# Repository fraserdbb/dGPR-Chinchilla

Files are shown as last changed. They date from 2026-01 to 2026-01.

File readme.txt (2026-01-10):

Novel Application of Stereotaxically Guided Dental Germinative 
Photodynamic Regulation in Chinchilla lanigera with 
Refractory Malocclusion.

Authored and Developed by Daniel B. B. Fraser

DOI: https://doi.org/10.5281/zenodo.18203469

~~~~~~~~~~~~~~~~~~~~~~~~~~~~~~~~~~~~~~~~~~~~~~~~~~~~~~~~~~~~~~~~~~~~~~~~~

This repository contains an open-source paper which covers photodynamic
therapy as a potential treatment option for refractory malocclusion
cases in chinchillas and other elodonts, particularly in cases of 
excessive growth, inadequate wear, and retrograde elongation.

There is also supporting documentation providing details on a
patient-specific stereotaxic device, dubbed Auriel, which was designed
to provide a stable, secure platform for the procedure. The model files
for this device are not released, to prevent it from being used against
advisement on chinchillas that it was not designed for.

Lastly, there is an attached software package for the validation of MCX
simulations graphed in the appendix of the paper. These are validation
structures with exact command line arguments for the user to enter, to
allow for exact reproducibility.

~~~~~~~~~~~~~~~~~~~~~~~~~~~~~~~~~~~~~~~~~~~~~~~~~~~~~~~~~~~~~~~~~~~~~~~~~

Further details on the software package can be found in the readme files
contained in each subfolder.

~~~~~~~~~~~~~~~~~~~~~~~~~~~~~~~~~~~~~~~~~~~~~~~~~~~~~~~~~~~~~~~~~~~~~~~~~

License & Copyright

This project is dual-licensed due to scope:

Software code (Python Scripts) are licenced under the GNU General Public
License v3.0 (GPLv3). You may copy, distribute, and modify the software as
long as you track the changes and release modifications under the same 
license.

Documentation and Papers (PDFs, Protocol Text, and Guide Specifications) 
are licensed under Creative Commons Attribution-ShareAlike 4.0
International (CC BY-SA 4.0). To view a copy of this license, visit 
https://creativecommons.org/licenses/by-sa/4.0/

~~~~~~~~~~~~~~~~~~~~~~~~~~~~~~~~~~~~~~~~~~~~~~~~~~~~~~~~~~~~~~~~~~~~~~~~~

Bibliography

The following works were cited in the development of this protocol,
hardware design, and simulation. For a formatted list with embedded links
download the main paper PDF, which is listed under the name
"Fraser_dGPR_Chinchilla_Protocol_2025_RELEASE.pdf"

Agostinis, P. et al. (2011). Photodynamic Therapy of Cancer: an Update. CA: a Cancer Journal for Clinicians, 61, 250-281. https://doi.org/10.3322/caac.20114

Anderson, R. R. & Parrish, J. A. (1983). Selective Photothermolysis: Precise Microsurgery by Selective Absorption of Pulsed Radiation. Science, 220(4596), 524-527. https://doi.org/10.1126/science.6836297

Bisland, S. K. & Burch, S. (2006). Photodynamic Therapy of Diseased Bone. Photodiagnosis and Photodynamic Therapy, 3(3), 147-155. https://doi.org/10.1016/s1572-1000(06)00036-6

Brenner, S. Z. G. et al. (2005) Clinical Anatomy, Radiography, and Computed Tomography of the Chinchilla Skull. Compendium on Continuing Education for the Practicing Veterinarian. 27(12), 933-943.

Brodbelt, D. C. et al. (2008). The Risk of Death: the Confidential Enquiry into Perioperative Small Animal Fatalities. Veterinary Anaesthesia and Analgesia, 35(5), 365-373. https://doi.org/10.1111/j.1467-2995.2008.00397.x

Capello, V. (2016). Diagnostic Imaging of Dental Disease in Pet Rabbits and Rodents. The Veterinary Clinics of North America. Exotic Animal Practice, 19(3), 757-782. https://doi.org/10.1016/j.cvex.2016.05.001

Cooper, G. (1975). Anatomy of the Guinea Pig. Harvard University Press. p. 151. ISBN 9780674031593.

Crossley, D. A. (2001). Dental Disease in Chinchillas in the UK. The Journal of Small Animal Practice, 42(1), 12-19. https://doi.org/10.1111/j.1748-5827.2001.tb01977.x

Dolmans, D. et al. (2003). Photodynamic Therapy for Cancer. Nature Reviews Cancer, 3, 380-387. https://doi.org/10.1038/nrc1071

Eriksson, A. R. & Albrektsson, T. (1983). Temperature Threshold Levels for Heat-Induced Bone Tissue Injury: A Vital-Microscopic Study in the Rabbit. The Journal of Prosthetic Dentistry, 50(1), 101-107. https://doi.org/10.1016/0022-3913(83)90174-9

Fang, Q. & Boas, D. A. (2009). Monte Carlo Simulation of Photon Migration in 3D Turbid Media Accelerated by Graphics Processing Units. Optics Express, 17(22), 20178-20190. https://doi.org/10.1364/oe.17.020178

Fu, Y & Jacques, S. L. (2011). Monte Carlo Simulation for Light Propagation in 3D tooth model. Optical Interactions with Tissues and Cells XXII, SPIE: Bellingham, WA, USA. https://doi.org/10.1117/12.873603

Greene, E. C. (1935). Anatomy of the Rat. Transactions of the American Philosophical Society, 27. https://doi.org/10.2307/1005513

Harada, H. et al. (1999). Localization of Putative Stem Cells in Dental Epithelium and their Association with Notch and EGF Signaling. The Journal of Cell Biology, 147(1), 105-120. https://doi.org/10.1083/jcb.147.1.105

Harris, K. et al. (2017). Endobronchial Ultrasound-Guidance for Interstitial Photodynamic Therapy of Locally Advanced Lung Cancer – A New Interventional Concept. Journal of Thoracic Disease, 9(8): 2613-2618. https://doi.org/10.21037/jtd.2017.07.45

Hisey, E., et al. (2024). Contrast Computed Tomography Dacryocystorhinography Identifies Nasolacrimal Duct Obstruction Secondary to Chronic Dental Disease in Two Chinchilla lanigera. Veterinary Ophthalmology, 28(3). https://doi.org/10.1111/vop.13281

Kato, T., et al. (2017). Nanoparticle Targeted Folate Receptor 1-Enhanced Photodynamic Therapy for Lung Cancer. Lung Cancer 113: 59-68. https://doi.org/10.1016/j.lungcan.2017.09.002

Krammer, B. (2001). Vascular Effects of Photodynamic Therapy. Anticancer Research 21(6B), 4271-4277.

Legendre, L. F. J. (2002). Malocclusions in Guinea Pigs, Chinchillas and Rabbits. The Canadian Veterinary Journal or La Revue Veterinaire Canadienne, 43(5), 385-390. 

Lennox, A. M., et al. (2021). 36 - Small Mammal Dentistry. Ferrets, Rabbits, and Rodents, 4th Edition: 514-535. ISBN 9780323484350, https://doi.org/10.1016/B978-0-323-48435-0.00036-8

Lovell, J. F. et al. (2011). Porphysome Nanovesicles Generated by Porphyrin Bilayers for Use as Multimodal Biophotonic Contrast Agents. Nature Mater, 10, 324-332. https://doi.org/10.1038/nmat2986

Mans, C. & Donnelly, T. M. (2021). 22 - Chinchillas. Ferrets, Rabbits, and Rodents, 4th Edition: 298-322. ISBN 9780323484350, https://doi.org/10.1016/B978-0-323-48435-0.00022-8

Natural History Museum of Los Angeles County (2020). Chinchilla lanigera Skull DICOM [Data Set]. MorphoSource. https://www.morphosource.org/concern/media/000114253

Philp, L. et al. (2019). Use of Porphysomes to Detect Primary Tumour, Lymph Node Metastases, Intra-Abdominal Metastases and as a Tool for Image-Guided Lymphadenectomy: Proof of Concept in Endometrial Cancer. Theranostics 9(9). 2727-2738. https://doi.org/10.7150/thno.31225

Ritzman, T. (2014). Diagnosis and Clinical Management of Gastrointestinal Conditions in Exotic Companion Mammals (Rabbits, Guinea Pigs, and Chinchillas) Veterinary Clinics of North America: Exotic Animal Practice 17(2), 179-194. https://doi.org/10.1016/j.cvex.2014.01.003

Sadar, M. J. & Mans, C. (2023). Hystricomorph Rodent Analgesia. The Veterinary Clinics of North America. Exotic animal practice 26(1) (2023): 175-186. https://doi.org/10.1016/j.cvex.2022.07.006

Sahovaler, A. et al. (2024). Nanoparticle-mediated Photodynamic Therapy as a Method to Ablate Oral Cavity Squamous Cell Carcinoma in Preclinical Models. Cancer Research Communications 4(3), 796-810. https://doi.org/10.1158/2767-9764.crc-23-0269

Shanshool, A. S. et al. (2022). Optical Properties and Fluence Distribution in Rabbit Head Tissues at Selected Laser Wavelengths. Materials, 15(16), 5696. https://doi.org/10.3390/ma15165696

Shinn, R. et al. (2021). Feasibility and Accuracy of 3D printed patient-specific skull contoured brain biopsy guides. Veterinary Surgery, 50: 933-943. https://doi.org/10.1111/vsu.13641

Suzuki, T. et al. (2020). Vascular Shutdown by Photodynamic Therapy Using Talaporfin Sodium. Cancers 12(9), 2396. https://doi.org/10.3390/cancers12092369

Wang, L. (2018). Solute Transport in the Bone Lacunar-Canalicular System (LCS). Current Osteoporosis Reports, 16(1), 32-41. https://doi.org/10.1007/s11914-018-0414-3

Wang, W. et al. (2025). Effects of Enrofloxacin Administered Subcutaneously or Orally on the Fecal Microbiota of Chinchillas (Chinchilla lanigera). Journal of Exotic Pet Medicine 52, 9-16. https://doi.org/10.1053/j.jepm.2024.10.003

Wilcox, H. H. (1950). Histology of the Skin and Hair of the adult chinchilla. The Anatomical Record, 108(3), 385-397. https://doi.org/10.1002/ar.1091080304

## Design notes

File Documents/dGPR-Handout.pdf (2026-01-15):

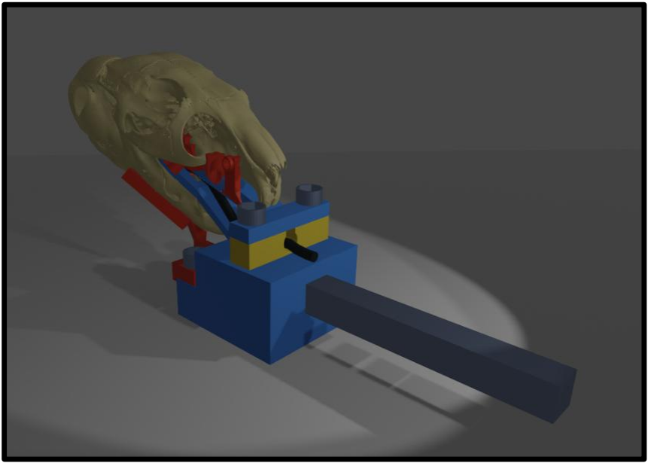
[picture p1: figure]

CC BY-SA 4.0

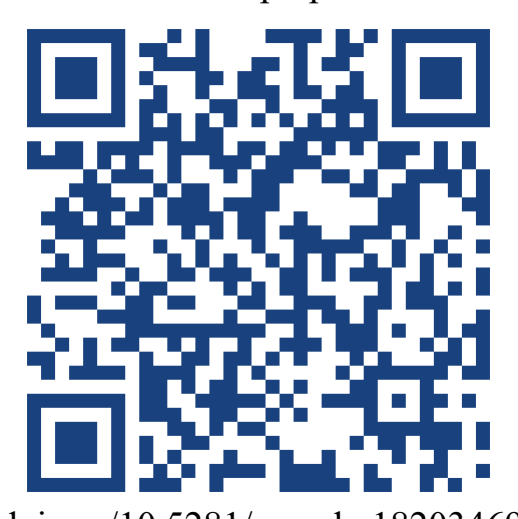
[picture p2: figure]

https://doi.org/10.5281/zenodo.18203469

Novel Application of Stereotaxically Guided Dental Germinative Photodynamic Regulation in

Chinchilla lanigera with Refractory Malocclusion.

Daniel B. B. Fraser

Dental Germinative Photodynamic Regulation (dGPR) is a theoretical photodynamic

technique for the treatment of refractory malocclusion in chinchillas (Chinchilla lanigera)

due to their high incidence rate of malocclusion (Crossley, 2001). This is an important

development as current techniques for refractory malocclusion are palliative, with - according to

statistical projections - practically no patients living for their full lifespan. Extrapolation from

current data on anesthetic risk suggests that a skilled veterinary surgeon could use this procedure

to achieve a significantly improved survival rate (Brodbelt et al., 2008).

Contributions of raw CT imagery (DICOMs) from chinchillas would greatly help with

safety testing and improvement of the guide frame; author contact information can be

found at the preprint landing page via the QR code.

Scan here for the full preprint and citations:

doi.org/10.5281/zenodo.18203469 Auriel Stereotaxic Guide Frame - Alpha Prototype

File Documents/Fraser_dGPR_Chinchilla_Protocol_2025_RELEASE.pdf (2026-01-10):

Novel Application of Stereotaxically Guided Dental Germinative Photodynamic Regulation in Chinchilla lanigera with Refractory Malocclusion. © 2026 by Daniel B. B. Fraser is licensed under CC BY-SA 4.0. To view a copy of this license, visit https://creativecommons.org/licenses/by-sa/4.0/

Novel Application of Stereotaxically Guided Dental Germinative Photodynamic Regulation in

Chinchilla lanigera with Refractory Malocclusion.

Daniel B. B. Fraser

10th January 2026

Daniel B. B. Fraser | 1

CC BY-SA 4.0
https://doi.org/10.5281/zenodo.18203469

Abstract

Dental Germinative Photodynamic Regulation (dGPR) is a theoretical photodynamic

technique for the treatment of refractory malocclusion in hypselodont species, primarily rodents

and lagomorphs, that results in a reduced rate of eruption. This proposal is focused on chinchillas

(Chinchilla lanigera) due to their high incidence rate of malocclusion (Crossley, 2001). This is an

important development as current techniques for refractory malocclusion are palliative, with -

according to statistical projections - practically no patients living for their full lifespan.

Extrapolation from current data on anesthetic risk suggests that a skilled veterinary surgeon

could use this procedure to achieve a significantly improved survival rate (Brodbelt et al., 2008).

Background and Clinical Need

Chinchillas (Chinchilla lanigera) possess hypselodont dentition, characterized by

continuous eruption throughout life (Hisey et al., 2024). In chinchillas, the germinative tissues of

the teeth are located at the base of the reserve crown (Brenner et al., 2005), the position of which

varies by tooth. The reserve crowns of the mandibular teeth are located deep in the mandible,

extending to the ventral margin of the mandible; the reserve crowns of the maxillary molars are

located just below the alveolar floor, bordering the infraorbital region and orbital cavity; the

reserve crowns of the maxillary incisors are located just below the surface at the lateral sides of

the incisive bone (Natural History Museum of Los Angeles County, 2020). Dental malocclusion,

where the rate of eruption exceeds the rate of wear, is a pervasive and often fatal condition in this

species (Mans & Donnelly, 2021).

The current standard of care involves repeated coronal reduction under general anesthesia

(Mans & Donnelly, 2021). Because coronal reduction only addresses the clinical signs of

malocclusion rather than the underlying pathology, treatments must be repeated at varying intervals for the remainder of the animal’s life in order to control pain and allow them to eat

unaided (Mans & Donnelly, 2021). This approach is strictly palliative and carries significant

cumulative anesthetic risk, as small mammals have higher perianesthetic mortality rates

compared to dogs and cats (Brodbelt et al., 2008). The common alternate approach, surgical

extraction, is invasive, physically traumatic, and prone to severe complications (Lennox et al.,

2021). To be specific, a chinchilla diagnosed at age four and managed via coronal reduction

theoretically faces more than 90 general anesthetic events within its natural lifespan (Legendre,

2002). Brodbelt et al. (2008) reported a mean per-anesthetic mortality rate of 3.29% in

chinchillas (n=334). At this rate, the cumulative statistical probability of anesthetic death over a

lifetime of palliative care exceeds 95%. While clinical reality is often truncated by earlier

euthanasia or fatal secondary effects (Crossley, 2001), this trajectory demonstrates that the

current standard of care is statistically terminal. Thus, a curative intervention that modulates the

rate of tooth growth is critically needed.

Proposed Solution and Hypothesis

I propose Dental Germinative Photodynamic Regulation (dGPR), my adaptation of

stereotaxically guided interstitial photodynamic therapy specific to hypselodont dentition, to

achieve precise partial ablation of the apical germinative tissue.

Hypothesis: dGPR can safely and effectively reduce the volume of active odontogenic

germ cells, thereby slowing the rate of tooth eruption to restore the equilibrium between growth

and wear, reducing or eliminating the need for repeated anesthetic interventions.

Unlike existing ablative techniques, this method aims to preserve functional tooth

structure while restoring physiological equilibrium.

Rationale for dGPR

Initial theoretical concepts involving direct thermal laser ablation are clinically non-

viable due to a high risk of collateral thermal damage to osseous tissue (Eriksson & Albrektsson,

1983), which is likely exacerbated due to the sub-millimeter thickness of several areas of the

bone, including the maxillary alveolus (Natural History Museum of Los Angeles County, 2020).

Photodynamic Therapy (PDT) utilizes a photosensitizing agent activated by non-thermal

light, inducing cell death via reactive oxygen species (Agostinis et al., 2011). This non-thermal

mechanism allows for intraosseous treatments without collateral osteonecrosis from heat damage

(Bisland & Burch, 2006). The dual-selective nature of this procedure enhances the precision of

the ablation application. The biological selectivity of photosensitizers, which preferentially

accumulate in metabolically active tissues, would cause them to gather in the germinative stem

cells due to their high rate of division (Dolmans et al., 2003; Harada et al., 1999). The spatial

selectivity of the light delivery via interstitial optic fiber would allow for tight control of the

ablation area within the biologically selected tissue. Additionally, the procedure would be as

minimally invasive as currently possible, as light delivery can be achieved via small-gauge

interstitial probes (Harris et al., 2017; Sahovaler et al., 2024).

A synergistic benefit of photodynamic therapy is that it can modulate the microvascular

environment within the targeted area (Krammer, 2001; Suzuki et al., 2020). This vascular

regulation restricts the metabolic supply to the niche, theoretically acting as a metabolic limiter

and preventing the compensatory proliferation of surviving stem cells. This reduction in

proliferation would then reduce the potential eruption rate governed by the reduced oxygen

supply, and the non-necrotic resolution allows for titratable, iterative treatments if required.

A key objective for further study is to optimize dosimetry, potentially through

fractionated light delivery, to preferentially induce apoptosis while minimizing necrosis. This

reduces the risk of severe inflammation and promotes controlled tissue reduction.

Methodology Outline: Stereotaxic Guidance

The deep intraosseous location of the germinative tissue necessitates sub-millimeter

accuracy. Small mammals like chinchillas are particularly sensitive to anesthetic use, thus the

guide designed for this protocol holds the head upright, allowing two surgeons to work in tandem

for significantly reduced anesthetic time. My proposed workflow integrates advanced imaging

alongside a patient-specific Auriel Stereotaxic Guide (for safety and design information, refer to

the separate document: Patient Specific Stereotaxic Guide Specifications for Dental Germinative

Photodynamic Regulation):

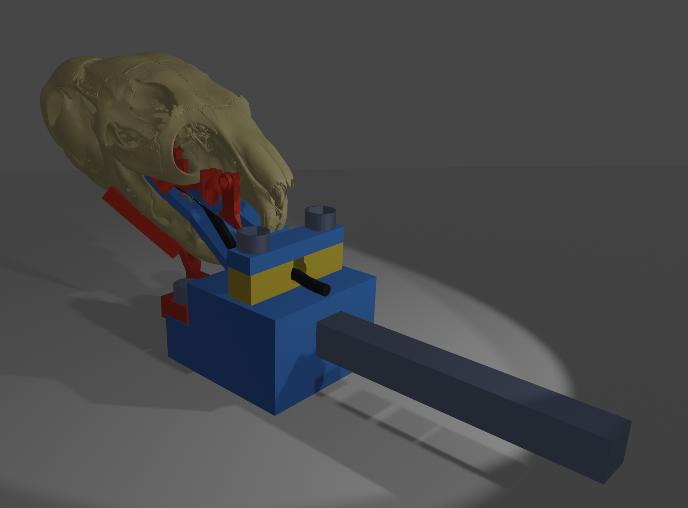
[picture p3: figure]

1. Computed Tomography (CT) will be

used to map the 3D volume and

location of the target germinative

tissue, given its proven efficacy over

other radiological methods for

rodents (Capello, 2016).

2. A 3D reconstruction and dosimetry

plan will be developed. Fabrication

of patient-specific, 3D-printed stereotaxic guides are necessary to ensure the

precision of the trajectory of the interstitial probe (Shinn et al., 2021).

3. The patient will be administered with a photosensitizer, with time differing

dependent on the selected photosensitizer. Chinchillas are likely more resistant to

Figure 1: Auriel Stereotactic Guide, Alpha Prototype Render the associated photosensitivity effects due to their thick coat (Wilcox, 1950), but

they should be kept in a low light environment to protect their eyes, ears, nose,

and paws. Being in a low light environment is not uncommon in their daily lives,

as they typically use hides, thus there should be little stress associated with this.

4. This is then followed by the surgical procedure:
- The patient is intubated, and their pharynx is packed with sterile gauze to

prevent aspiration.

- This is followed by standard aseptic preparation of the operative site, as it

is shaved for clean contact with external guides.

- The stereotaxic guide is then fitted, first the intra-oral mandibular block is

placed. The maxillary block is then fixed to the maxilla. The intubation

tube is placed into the intubation block which is inserted between the

mandibular and maxillary blocks. Those blocks are then affixed to one

another via M3 screws. Finally, the external mandibular blocks are

attached to the intra-oral mandibular block.

- The guides are then used to make incisions and drill in the predetermined

trajectories towards the germinative apices, these guides are lined with

surgical steel, for structural integrity given drill proximity and to isolate

the operational zone optically. A high torque/low speed drill alongside

cooled saline will be used to manage temperature and prevent

osteonecrosis caused by heat, which can occur at temperatures as low as

47°C (Eriksson & Albrektsson, 1983).

- The optic fiber (likely a capped cylindrical diffuser for balanced coverage

with a dark zone for avoidance of sensitive tissues) is inserted into the

germinative apex, and the photodynamic diode activated. Fractionated

light delivery will be ideal to mitigate heat and maximize reactive oxygen

species efficiency.

- The previous two steps can be repeated for every tooth, the guide makes it

possible for two veterinarians to work in tandem, one managing each side

of the face, to halve the time spent under anesthesia.

- Once a germinative apex has been given the calculated light dosage, the

optic fiber is removed, the drill burr in the bone is packed with resorbable

gelatin sponge, and associated incisions are sutured. Skin sutures should

be subcuticular to prevent damage via scratching.

- Standard analgesia, such as Meloxicam (Sadar & Mans, 2023), should be

administered immediately post-operatively, as chinchillas are sensitive to

pain and may refuse to eat, causing gastrointestinal stasis, which can be

fatal.

- Prophylactic antibiotics approved for use in chinchillas, an example being

Enrofloxacin (Wang et al., 2025), should also be administered post-

operatively to prevent infection.

- Critical care (Oxbow, Herbivore variant), or another clinically validated

syringe food, should be administered via syringe within two hours of

waking if the patient does not eat on their own. This rapid intervention is necessary for prevention of gastrointestinal stasis and hepatic lipidosis

(Ritzman, 2014).

Photosensitizer Selection

For live cases, the photosensitizer delivery method that appears most clinically viable are

porphysomes. This is due to their accumulation in inflamed tissues which mirror the enhanced

permeability and retention seen in tumors (Philp et al., 2019), which would theoretically

concentrate the photodynamic effect on the inflamed, heavily vascularized, germinative niche.

Additionally, the accumulation of porphysomes in inflamed tissue may have a rebalancing effect

on the tissue, as the most inflamed tissues and most vascularized tissues would be preferentially

targeted, which I hypothesize would add a biological targeting mechanism for the most active

germinative tissue. Additionally, porphysomes absorb 671nm light most effectively (Lovell et

al., 2011), which is scattered by cortical bone and dentin (Shanshool et al., 2022), allowing the

photons to pass over target cells multiple times, and acting as a safety feature which prevents

damage to cells external to the germinative apex. An additional feature of porphysomes is their

fluorescence profile. They begin as nanostructures (vesicles), with little fluorescence (Lovell et

al., 2011). When there is uptake of porphysomes in cells, they are dissociated into their active

form, which is highly fluorescent. This allows for fluorescence imaging prior to an operation to

ensure the germinative apex internalized porphysomes prior to surgery, to ensure no unnecessary

operation takes place if the drug delivery fails.

For the cadaver study, this would not be feasible as the blood cannot carry the

porphysomes to their destination in the absence of a pulse, thus I have selected methylene blue

for its similar light absorbance (~665nm), which would be injected interstitially into the germinative apex through the drill path. This would allow assessment of the light dispersion in

the space, thus enabling review of the effectiveness of different trajectories.

Risk Mitigation and Contingency

The primary technical risk is the

precise calibration of the ablation volume. If

ablation is excessive and wear exceeds the

slowed eruption rate, the ideal contingency is

supplemental or full syringe feeding. This

outcome is preferable to the cumulative risks

of lifelong anesthesia or euthanasia, which are

currently unavoidable in such cases. Due to the

non-necrotic resolution of PDT, the structural

integrity of the alveolus is predicted to be

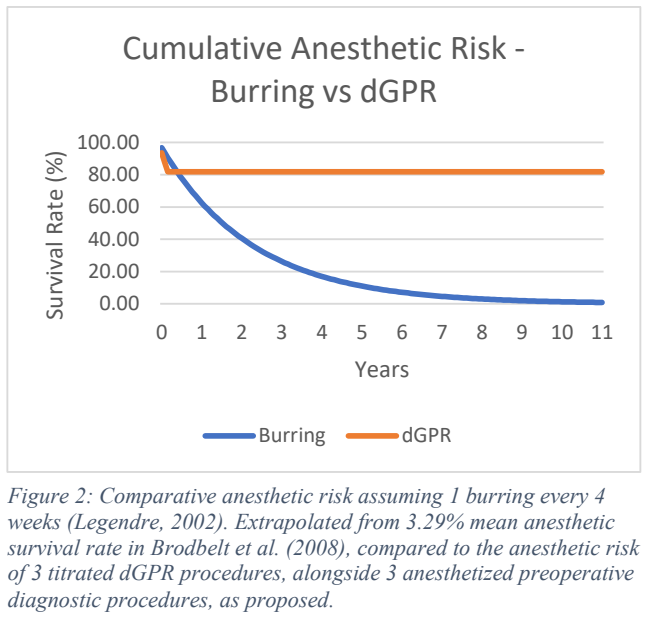
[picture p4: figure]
diagnostic procedures, as proposed.; Survival Rate (%); Years; Cumulative Anesthetic Risk - Burring vs dGPR; Burring; dGPR

preserved based on preliminary Monte Carlo simulations (Appendix). This then allows for

iteration and titration of the procedure, which enables the clinical team to adjust the eruption rate

over multiple sessions, without the trauma or pain of extraction or burring. While iterative

therapy does reintroduce additional anesthetic episodes, this finite intervention protocol

represents a statistically drastic reduction in cumulative risk compared to indefinite, high-

frequency anesthetic required for current palliative management. Limiting the protocol to a series

of three sessions, with the necessary three pre-operative diagnostic procedures which would be

necessary for CT, confines the cumulative anesthetic risk to <20%, which is an >75%

improvement in projected mortality rates when compared to standard palliative care (figure 2),

Figure 2: Comparative anesthetic risk assuming 1 burring every 4 weeks (Legendre, 2002). Extrapolated from 3.29% mean anesthetic survival rate in Brodbelt et al. (2008), compared to the anesthetic risk of 3 titrated dGPR procedures, alongside 3 anesthetized preoperative while simultaneously eliminating the chronic welfare impact of indefinite monthly anesthetic

induction.

Research Objectives and Next Steps

The immediate goal is to transition this theoretical framework into a pilot study. The

proposed initial phases are:

1. Phase 1 (Ex Vivo): Test the accuracy of 3D-printed surgical guides, and establish

preliminary dosimetry parameters (exact light and photosensitizer dosages, and

tissue response to the methodology)

2. Phase 2 (Pilot In Vivo): Pending ethical approval, the full dGPR protocol would

be performed on clinical cases with guarded or poor prognoses (e.g. candidates

for euthanasia) directly before administering humane euthanasia. Both procedures

would be performed under the same anesthetic episode, without the patient being

awoken.

3. Phase 3 (In Vivo Survival Studies): Assuming photosensitizer and

photodynamic efficacy in the pilot study, the treatment would then be performed

on advanced in vivo cases with post-operative progress updates.

This research is a translational effort to adapt established biophotonic oncological

technology to solve a persistent, critical challenge in exotic companion mammal dentistry

through precision, patient specific engineering, which, if successful, could be translated across

species with similar dentition.

I am actively seeking academic mentorship and institutional collaboration to progress this

work from a theoretical framework to ethical pilot testing. I would be deeply grateful for any guidance or introduction to faculty with interest in translational oncology or exotic mammal

dentistry.

Acknowledgement

I would like to thank Shawn R. S. Del Carmen for the initial conceptual dialogue in

which he proposed thermal laser ablation as a potential treatment for refractory malocclusion.

These discussions served as the catalyst for my research into other non-thermal, light-based,

oncological techniques, which led to my development of this protocol as a safer alternative for

germinative tissue modulation.

Appendix: Preliminary Monte Carlo Simulations

Monte Carlo simulations were run to determine the safety profile of differing fluence ranges. These simulations used the console version of MCX (Fang & Boas, 2009) using 25μm voxels and 500 million photons, generated with the use of a workstation using an Intel 13700kf central processing unit, 64GB of RAM, and a Nvidia rtx 4090 graphics card. JSON simulation configuration files, model files, and the programs used to generate the shown images are in an attached file.
The following are Monte Carlo simulations run on areas considered to be of the highest risk to sensitive structures nearby.
Both models used hybrid optical data from various sources. Notably, both models use parameters from rabbit bone, rabbit neural tissue (Shanshool et al., 2022), and human dental pulp data (Fu & Jacques, 2011), as these are the most relevant figures to the simulation. Materials intended to be opaque, like the fiber coating and resin guide with steel inlay, were assumed to be opaque, while the fiber tip was assumed to be near transparent.
The threshold figure for partial apoptosis has a basis in Kato et al. (2017), and the near-complete apoptosis threshold was adapted from Kato et al. (2017) alongside Sahovaler et al. (2024)

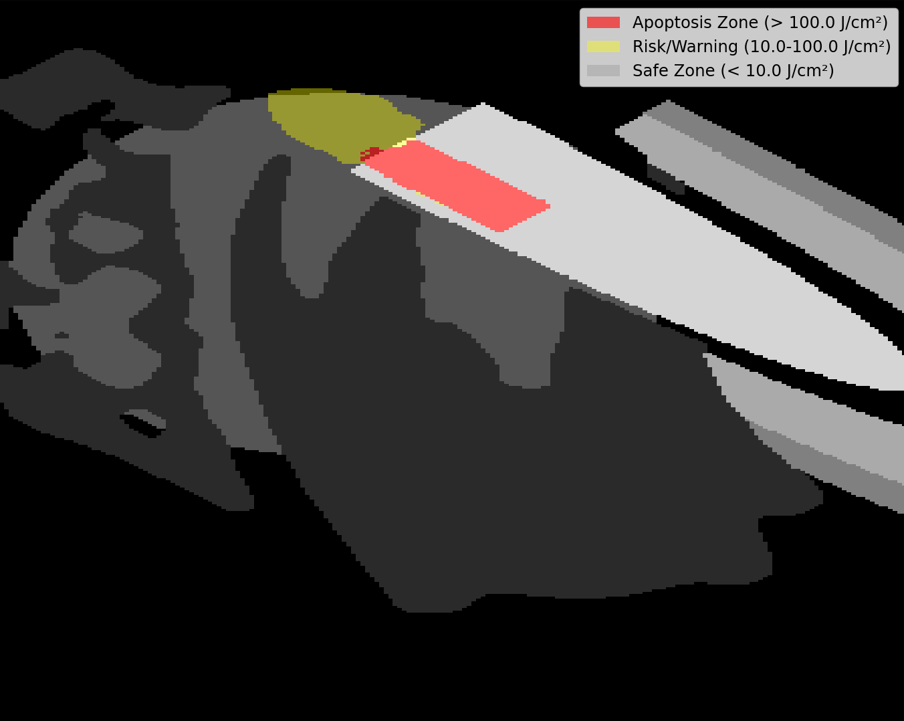
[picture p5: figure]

Figure 3: Monte Carlo Simulation of the Posterior Maxillary Molar, using an incident dose of 20J/cm²

The posterior maxillary molar was selected due to the thickness of the alveolar bone in the area, as well as its proximity to the cranial vault. Prior simulations were used as design challenges, primarily the reserve crown of the molar, which was penetrated by the drill due to necessity, would have been vulnerable to damage from the diode. This was mitigated via the coating of the sides of the cylindrical diffuser, with a semicircular window left open at the tip of the diode to more precisely target the germinative tissue and supporting vasculature with minimal collateral damage.

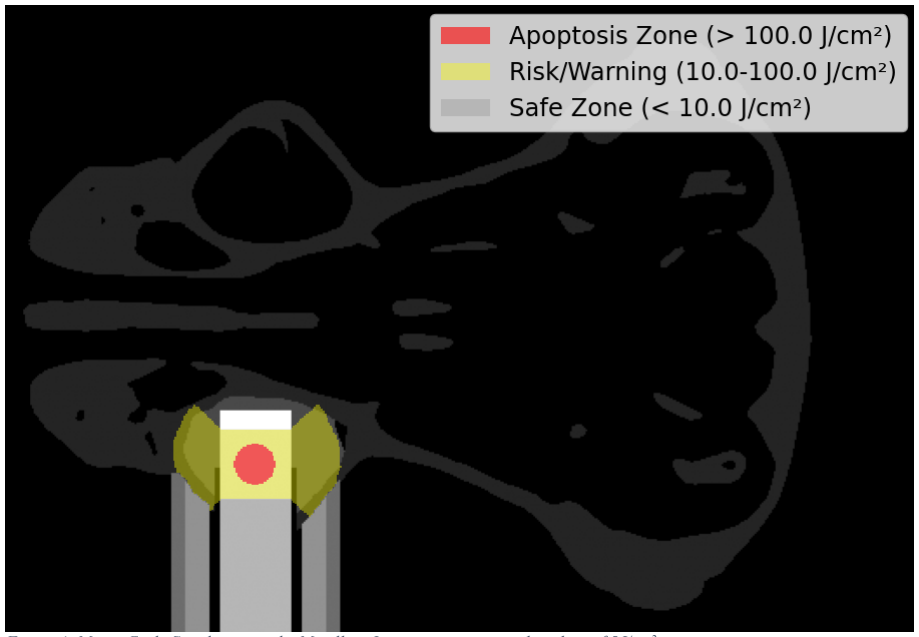
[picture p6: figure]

Figure 4: Monte Carlo Simulation on the Maxillary Incisor, using an incident dose of 5J/cm²

The maxillary incisor was selected for its proximity to the nasolacrimal duct. As can be seen, the fluence reached the surrounding bone, however, this is acceptable because of the physiology of bone tissue. Even under inflammatory conditions, osteocytes only intake solutes from the lacunar-canalicular system - and thus only have an intake of particles up to 17nm in size (Wang, 2018), meaning they will never be at risk of saturation with porphysomes due to their approximately 100nm size (Lovell et al., 2011). This acts as a protective effect for the bone, limiting the damage it could take to thermal sources only, which will not be relevant below 50J/cm² with fractionated delivery.

Of course, all fluence statistics displayed here are preliminary and will almost certainly be refined with ex vivo and pilot studies. Additionally, the fiber coating can, and likely will, be adjusted to accommodate any vital structures that must be avoided.

It should be noted that the simulations used time intervals as small as 5 nanoseconds, thus these simulations show the intended final light dosage for dentition like this, but not the time interval, as a 5 nanosecond pulse would make an extremely high peak power density, potentially causing a shockwave as the photosensitizer in the pulp absorbs light so quickly, creating pockets of high energy which quickly turn into photothermal and photomechanical action (Anderson & Parrish, 1983), which represent energy not used for photochemical release of reactive oxygen species.

For ideal dosage, the timing would need to be stretched to a much longer interval, like 10ms pulses with 50ms thermal relaxation periods (more detailed calculations would have to be performed to determine the true ideal intervals, preferably with verified optical properties for relevant tissues), which would be barely noticeable to the surgeon and not significantly increase operative time.

This kind of interval schedule could be easily managed by an inexpensive microcontroller circuit, which would activate or inactivate the diode circuit at the precise intervals. By using this microcontroller architecture, the procedure could be further tailored to the patient’s specific pathology by changing the overall duration of light delivery while maintaining low material cost. With a procedure like this, the anesthetic time is determined by how fast the surgeon can drill, as each tooth treatment would be 0.6 seconds (or similarly short depending on the patient’s pathology), thus reducing patient risk by truncating procedure time.

Works cited

Agostinis, P. et al. (2011). Photodynamic Therapy of Cancer: an Update. CA: a Cancer Journal for Clinicians, 61, 250-281. https://doi.org/10.3322/caac.20114

Anderson, R. R. & Parrish, J. A. (1983). Selective Photothermolysis: Precise Microsurgery by Selective Absorption of Pulsed Radiation. Science, 220(4596), 524-527. https://doi.org/10.1126/science.6836297

Bisland, S. K. & Burch, S. (2006). Photodynamic Therapy of Diseased Bone. Photodiagnosis and Photodynamic Therapy, 3(3), 147-155. https://doi.org/10.1016/s1572-1000(06)00036-6 (https://doi.org/10.1016/s1572-1000(06)00036-6)

Brenner, S. Z. G. et al. (2005) Clinical Anatomy, Radiography, and Computed Tomography of the Chinchilla Skull. Compendium on Continuing Education for the Practicing Veterinarian. 27(12), 933-943.

Brodbelt, D. C. et al. (2008). The Risk of Death: the Confidential Enquiry into Perioperative Small Animal Fatalities. Veterinary Anaesthesia and Analgesia, 35(5), 365-373. https://doi.org/10.1111/j.1467-2995.2008.00397.x

Capello, V. (2016). Diagnostic Imaging of Dental Disease in Pet Rabbits and Rodents. The Veterinary Clinics of North America. Exotic Animal Practice, 19(3), 757-782. https://doi.org/10.1016/j.cvex.2016.05.001

Cooper, G. (1975). Anatomy of the Guinea Pig. Harvard University Press. p. 151. ISBN 9780674031593.

Crossley, D. A. (2001). Dental Disease in Chinchillas in the UK. The Journal of Small Animal Practice, 42(1), 12-19. https://doi.org/10.1111/j.1748-5827.2001.tb01977.x

Dolmans, D. et al. (2003). Photodynamic Therapy for Cancer. Nature Reviews Cancer, 3, 380-
387. https://doi.org/10.1038/nrc1071

Eriksson, A. R. & Albrektsson, T. (1983). Temperature Threshold Levels for Heat-Induced Bone Tissue Injury: A Vital-Microscopic Study in the Rabbit. The Journal of Prosthetic Dentistry, 50(1), 101-107. https://doi.org/10.1016/0022-3913(83)90174-9

Fang, Q. & Boas, D. A. (2009). Monte Carlo Simulation of Photon Migration in 3D Turbid Media Accelerated by Graphics Processing Units. Optics Express, 17(22), 20178-20190. https://doi.org/10.1364/oe.17.020178

Fu, Y & Jacques, S. L. (2011). Monte Carlo Simulation for Light Propagation in 3D tooth model. Optical Interactions with Tissues and Cells XXII, SPIE: Bellingham, WA, USA. https://doi.org/10.1117/12.873603

Greene, E. C. (1935). Anatomy of the Rat. Transactions of the American Philosophical Society,
27. https://doi.org/10.2307/1005513

Harada, H. et al. (1999). Localization of Putative Stem Cells in Dental Epithelium and their Association with Notch and EGF Signaling. The Journal of Cell Biology, 147(1), 105-
120. https://doi.org/10.1083/jcb.147.1.105

Harris, K. et al. (2017). Endobronchial Ultrasound-Guidance for Interstitial Photodynamic Therapy of Locally Advanced Lung Cancer – A New Interventional Concept. Journal of Thoracic Disease, 9(8): 2613-2618. https://doi.org/10.21037/jtd.2017.07.45

Hisey, E., et al. (2024). Contrast Computed Tomography Dacryocystorhinography Identifies Nasolacrimal Duct Obstruction Secondary to Chronic Dental Disease in Two Chinchilla lanigera. Veterinary Ophthalmology, 28(3). https://doi.org/10.1111/vop.13281

Kato, T., et al. (2017). Nanoparticle Targeted Folate Receptor 1-Enhanced Photodynamic Therapy for Lung Cancer. Lung Cancer 113: 59-68. https://doi.org/10.1016/j.lungcan.2017.09.002

Krammer, B. (2001). Vascular Effects of Photodynamic Therapy. Anticancer Research 21(6B), 4271-4277.

Legendre, L. F. J. (2002). Malocclusions in Guinea Pigs, Chinchillas and Rabbits. The Canadian Veterinary Journal or La Revue Veterinaire Canadienne, 43(5), 385-390.

Lennox, A. M., et al. (2021). 36 - Small Mammal Dentistry. Ferrets, Rabbits, and Rodents, 4th Edition: 514-535. ISBN 9780323484350, https://doi.org/10.1016/B978-0-323-48435-0.00036-8 (https://doi.org/10.1016/B978-0-323-48435-0.00036-8)

Lovell, J. F. et al. (2011). Porphysome Nanovesicles Generated by Porphyrin Bilayers for Use as Multimodal Biophotonic Contrast Agents. Nature Mater, 10, 324-332. https://doi.org/10.1038/nmat2986

Mans, C. & Donnelly, T. M. (2021). 22 - Chinchillas. Ferrets, Rabbits, and Rodents, 4th Edition: 298-322. ISBN 9780323484350, https://doi.org/10.1016/B978-0-323-48435-0.00022-8

Natural History Museum of Los Angeles County (2020). Chinchilla lanigera Skull DICOM [Data Set]. MorphoSource. https://www.morphosource.org/concern/media/000114253

Philp, L. et al. (2019). Use of Porphysomes to Detect Primary Tumour, Lymph Node Metastases, Intra-Abdominal Metastases and as a Tool for Image-Guided Lymphadenectomy: Proof of Concept in Endometrial Cancer. Theranostics 9(9). 2727-2738. https://doi.org/10.7150/thno.31225

Ritzman, T. (2014). Diagnosis and Clinical Management of Gastrointestinal Conditions in Exotic Companion Mammals (Rabbits, Guinea Pigs, and Chinchillas) Veterinary Clinics of

North America: Exotic Animal Practice 17(2), 179-194. https://doi.org/10.1016/j.cvex.2014.01.003

Sadar, M. J. & Mans, C. (2023). Hystricomorph Rodent Analgesia. The Veterinary Clinics of North America. Exotic animal practice 26(1) (2023): 175-186. https://doi.org/10.1016/j.cvex.2022.07.006

Sahovaler, A. et al. (2024). Nanoparticle-mediated Photodynamic Therapy as a Method to Ablate Oral Cavity Squamous Cell Carcinoma in Preclinical Models. Cancer Research Communications 4(3), 796-810. https://doi.org/10.1158/2767-9764.crc-23-0269

Shanshool, A. S. et al. (2022). Optical Properties and Fluence Distribution in Rabbit Head Tissues at Selected Laser Wavelengths. Materials, 15(16), 5696. https://doi.org/10.3390/ma15165696

Shinn, R. et al. (2021). Feasibility and Accuracy of 3D printed patient-specific skull contoured brain biopsy guides. Veterinary Surgery, 50: 933-943. https://doi.org/10.1111/vsu.13641

Suzuki, T. et al. (2020). Vascular Shutdown by Photodynamic Therapy Using Talaporfin Sodium. Cancers 12(9), 2396. https://doi.org/10.3390/cancers12092369

Wang, L. (2018). Solute Transport in the Bone Lacunar-Canalicular System (LCS). Current Osteoporosis Reports, 16(1), 32-41. https://doi.org/10.1007/s11914-018-0414-3

Wang, W. et al. (2025). Effects of Enrofloxacin Administered Subcutaneously or Orally on the Fecal Microbiota of Chinchillas (Chinchilla lanigera). Journal of Exotic Pet Medicine 52, 9-16. https://doi.org/10.1053/j.jepm.2024.10.003

Wilcox, H. H. (1950). Histology of the Skin and Hair of the adult chinchilla. The Anatomical Record, 108(3), 385-397. https://doi.org/10.1002/ar.1091080304

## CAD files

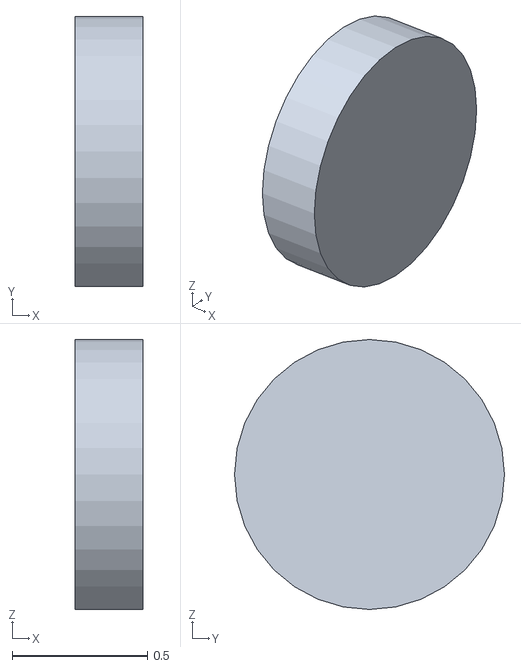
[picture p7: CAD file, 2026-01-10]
Graph-Validation-Package/Maxillary_Incisor/fiberCap.stl
0.25 x 1.00 x 1.00

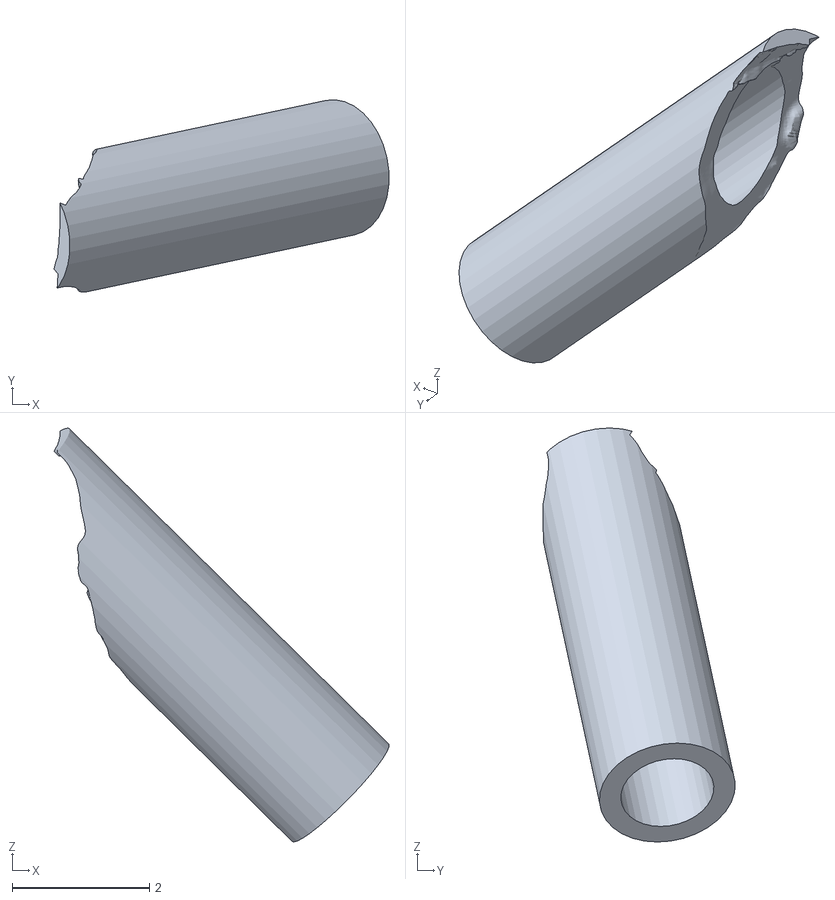
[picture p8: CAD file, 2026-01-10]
Graph-Validation-Package/Maxillary_molar/steel.stl
4.87 x 2.80 x 6.02

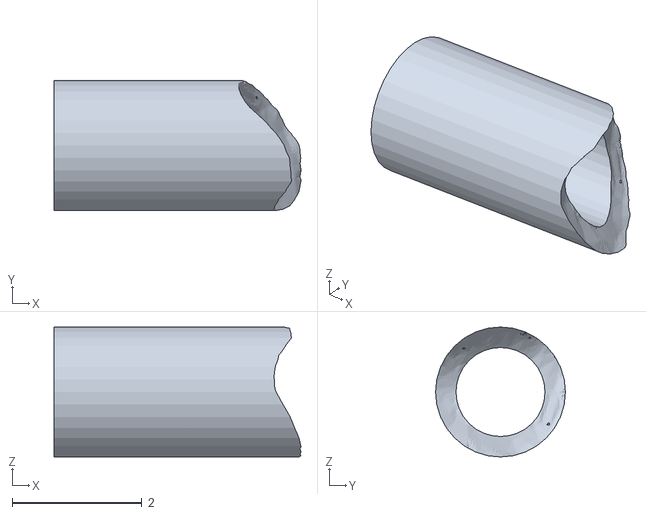
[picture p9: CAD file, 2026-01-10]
Graph-Validation-Package/Maxillary_Incisor/steel.stl
3.80 x 2.00 x 2.00

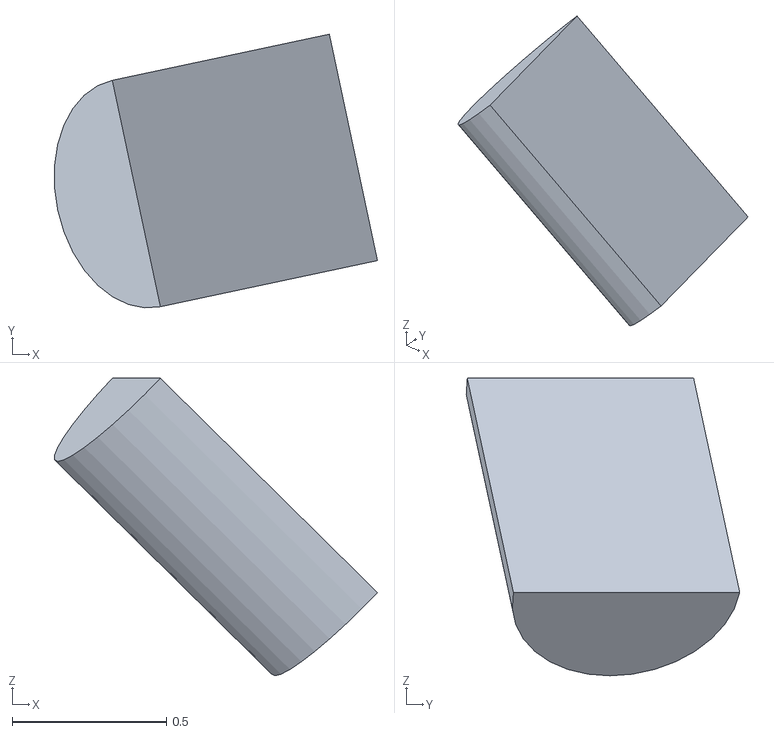
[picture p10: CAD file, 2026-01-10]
Graph-Validation-Package/Maxillary_molar/fiberUncoated.stl
1.05 x 0.887 x 0.964

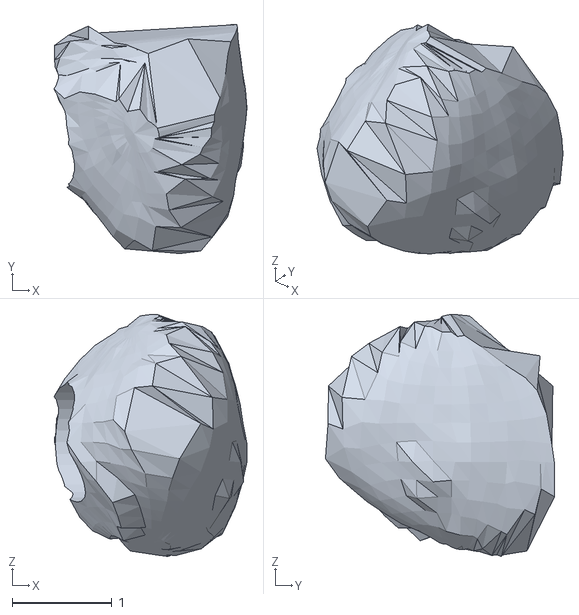
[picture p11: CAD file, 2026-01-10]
Graph-Validation-Package/Maxillary_Incisor/pulp.stl
1.93 x 2.29 x 2.42

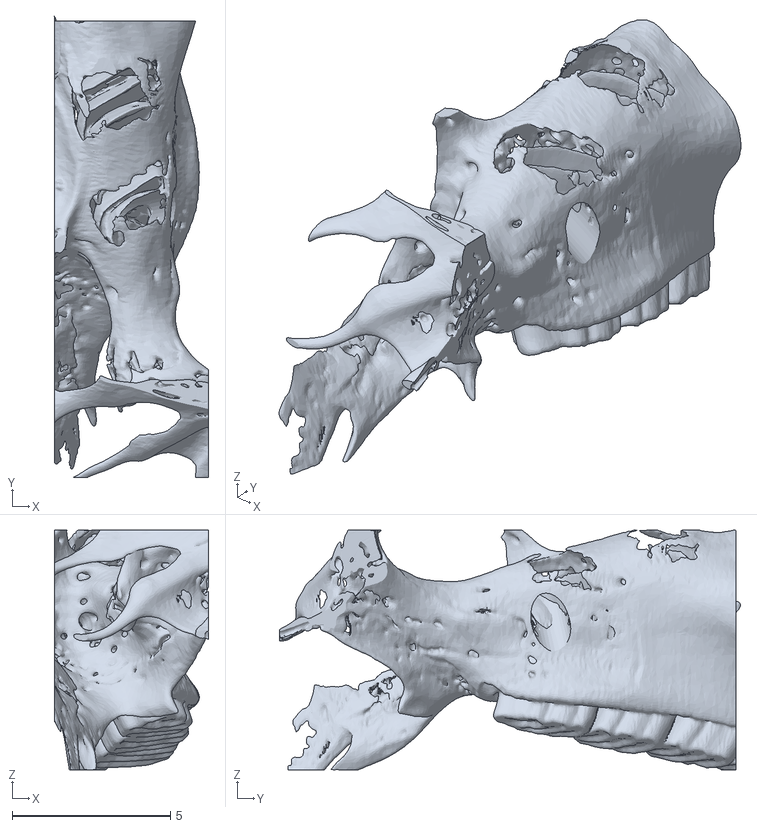
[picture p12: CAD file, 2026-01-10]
Graph-Validation-Package/Maxillary_molar/maxilla_fixed.stl
4.88 x 14.6 x 7.58

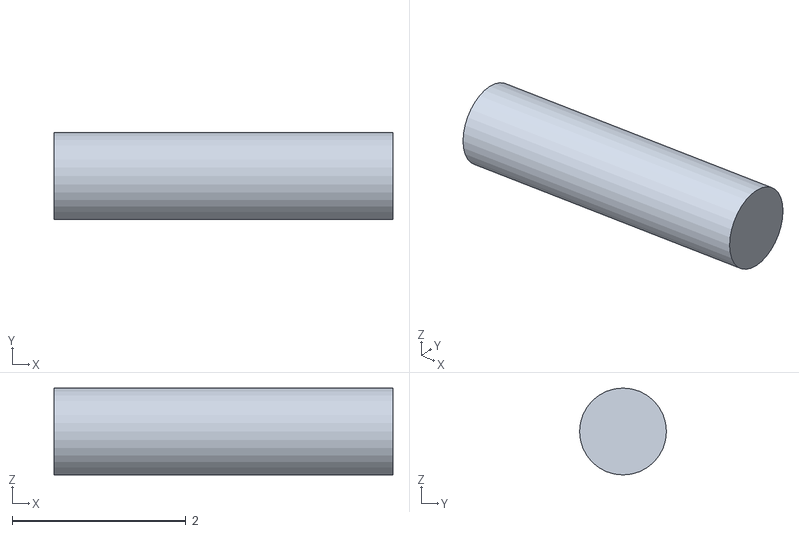
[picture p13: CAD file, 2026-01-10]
Graph-Validation-Package/Maxillary_Incisor/fiberCoated.stl
3.90 x 1.00 x 1.00

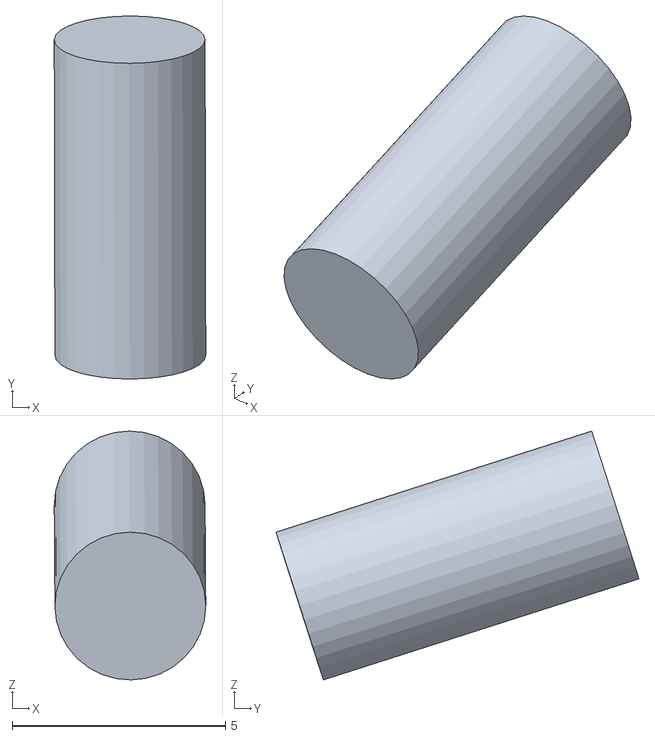
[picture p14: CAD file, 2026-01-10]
Graph-Validation-Package/Maxillary_molar/pulp.stl
3.55 x 8.51 x 5.83

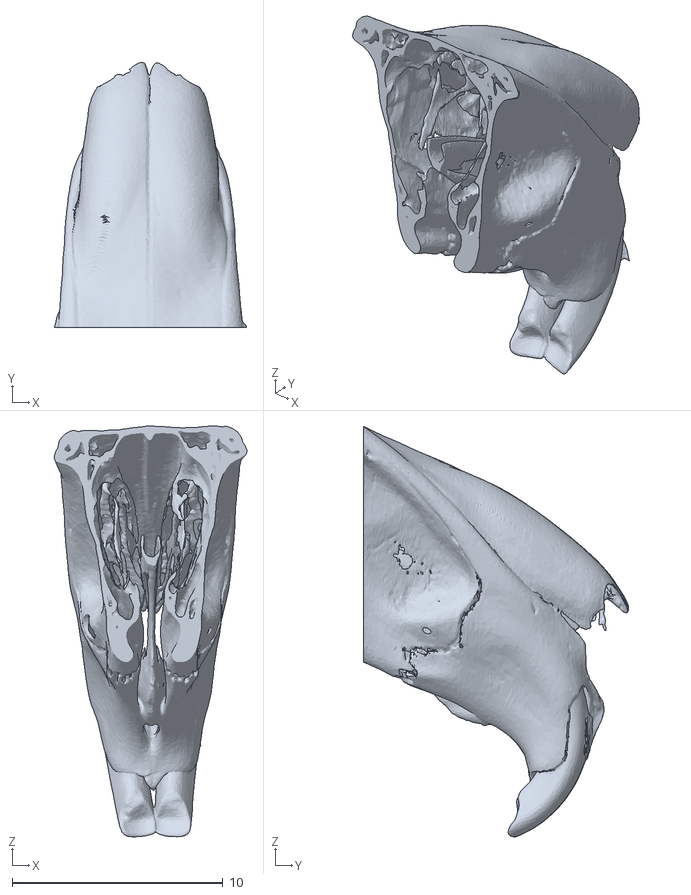
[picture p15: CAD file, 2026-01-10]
Graph-Validation-Package/Maxillary_Incisor/maxilla_fixed.stl
9.13 x 12.6 x 19.5

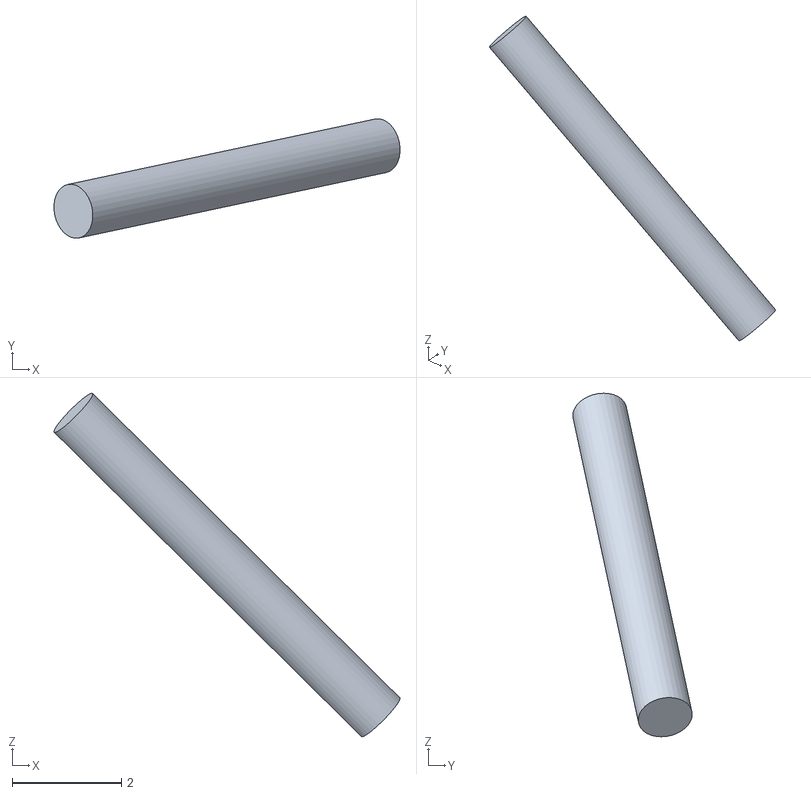
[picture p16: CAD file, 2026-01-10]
Graph-Validation-Package/Maxillary_molar/fiberCoated.stl
6.33 x 2.18 x 6.28

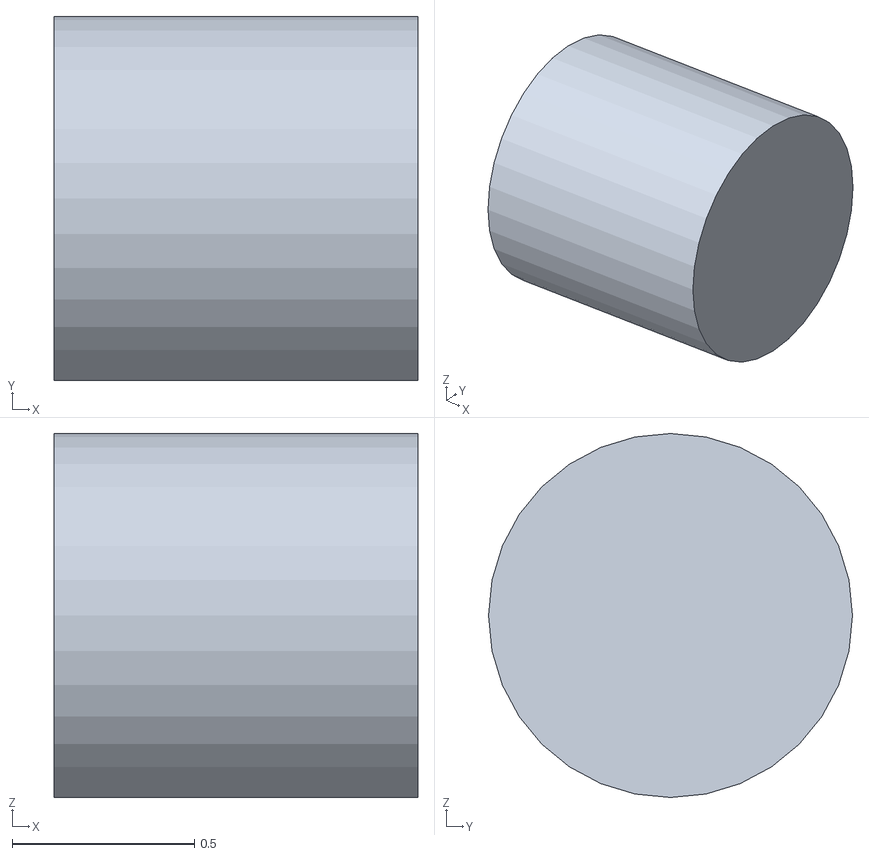
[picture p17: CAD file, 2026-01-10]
Graph-Validation-Package/Maxillary_Incisor/fiberUncoated.stl
1 x 1.00 x 1.00

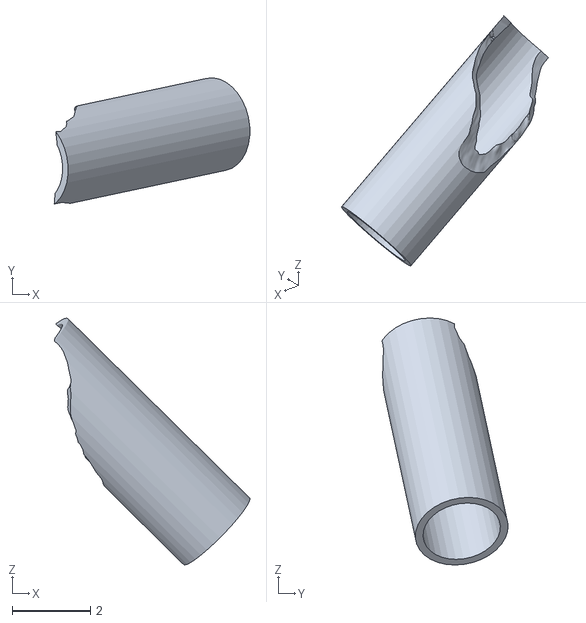
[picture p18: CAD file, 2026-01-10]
Graph-Validation-Package/Maxillary_molar/resin.stl
5.00 x 3.22 x 6.31

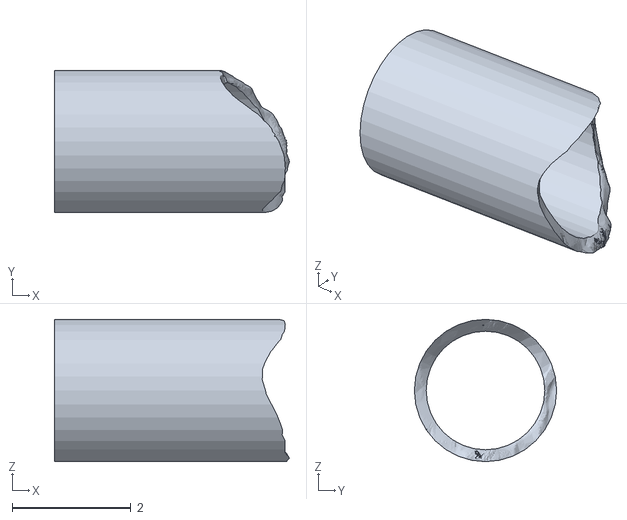
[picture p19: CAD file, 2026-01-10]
Graph-Validation-Package/Maxillary_Incisor/resin.stl
3.96 x 2.40 x 2.40

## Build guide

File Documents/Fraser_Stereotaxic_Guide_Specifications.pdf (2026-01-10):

Daniel B. B. Fraser | 1

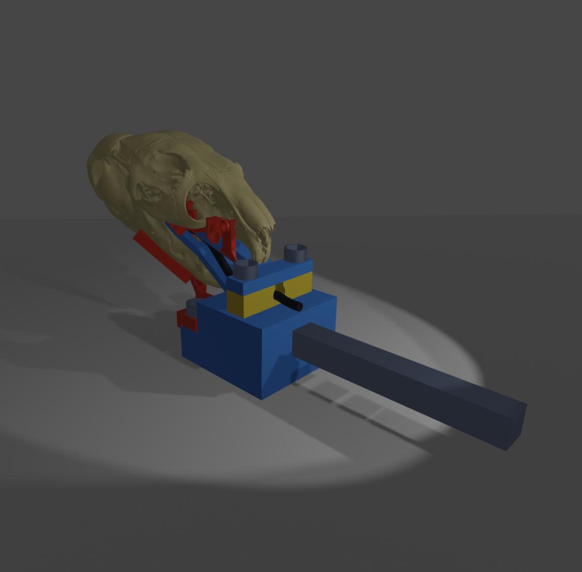
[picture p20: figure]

CC BY-SA 4.0

Patient Specific Stereotaxic Guide Specifications for Dental Germinative Photodynamic Regulation Daniel B. B. Fraser
10th January 2026

Project Scope:
This document covers design specifications for an alpha-stage dry-bone prototype of a novel stereotaxic surgical guide, designated the Auriel Stereotaxic Guide. The system is engineered to accommodate the precision requirements of Dental Germinative Photodynamic Regulation (dGPR), which is a theoretical therapeutic protocol designed to arrest retrograde root elongation using targeted photodynamic therapy for stem cell apoptosis.
The clinical goal of this frame is to facilitate minimally invasive access to root apices without the need for traumatic extractions, with the extreme precision required to isolate targets like the root apices.
Data Source: Chinchilla lanigera. cranium and mandible models sourced from the Natural History Museum of Los Angeles County via MorphoSource.org (https://www.morphosource.org/concern/media/000114253)

Figure 1

Prototype Status

To reiterate, the current iteration is a prototype constructed with simplified geometry as a functional proof of concept, modelled on dry skeletal data. In future stages, intended for cadaver studies or live patients, edges (particularly those that touch soft tissue) will be rounded to prevent mucosal injury. Additionally, future models will have a surface offset in areas with soft tissue (such as the skin and muscle around the outer surface of the mandible). Certain elements, particularly the external mandibular blocks, are depicted in reduced forms for clarity, a clinical version will have additional reinforcement to maximize rigidity under surgical load.

Device Components

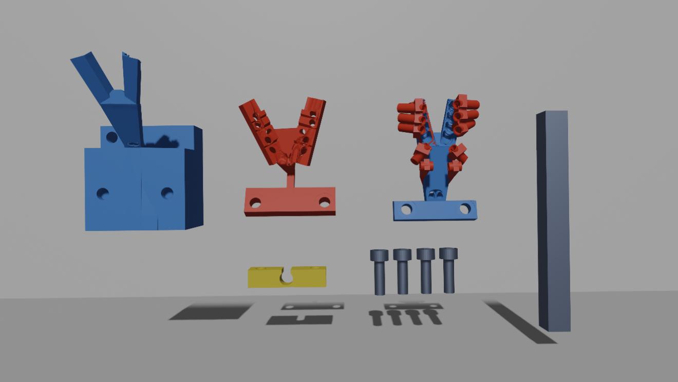
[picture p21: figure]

Figure 2 displays the components of the device. The stereotaxic guide is composed of four primary pieces (after the metal rod is mounted, which can be done with surgically appropriate adhesives).

Note: the maxillary barrels are depicted with cylindrical ends for visual clarity, these would have to be refined before fabrication using a Boolean difference operation (with a 1mm offset to account for shrinkage of print material) to produce a surface that correctly conforms to the patient’s maxilla.

The base of the guide (leftmost, solid blue) is the housing for the metal rod, which also makes it the mounting point between the system and a surgical table clamp. The base also functions as the intra-oral fixation point, providing a direct link between the surgical clamp and the chinchilla’s mandible.

Figure 2

The intubation guide block (bottom-left, yellow), allows the intubation tube through the stereotaxic fixation device, with a keyhole design to allow it to be affixed after intubation. It was additionally designed with significant clearance to enable rapid access to the airway and emergency extubation when necessary.

The external mandibular blocks (second from the left, red) guide the surgeon’s drill down a precalculated path to the germinative center of the chinchilla’s tooth. The barrels should be fitted with surgical-grade steel inlays prior to use in order to prevent the drill from damaging the resin and introducing fragments into the chinchilla’s mandible. They have a separation from the bone at the masseter’s insertion to prevent damage or compression of the facial artery and vein, given its position aligns with related species (Greene, 1935; Cooper, 1975; Natural History Museum of Los Angeles County, 2020).

The maxillary block (third from the left) is a fixation device with attached drill guides. The fixation segment conforms to the teeth to form a solid lock. The barrels are built onto the fixation device (their current design would require reinforcement prior to use) and should be fitted with a steel lining in order to prevent damage to the barrels from the drill. The guides on the maxillary block were designed for palpability, so the surgeon can feel where they need to cut for the most direct path to the germinative centers.

Lastly, the device uses four 10mm M3 screws for structural stability.

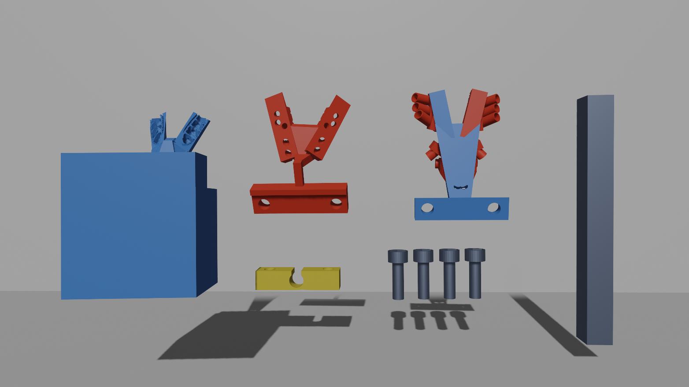
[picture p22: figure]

Clinical Justification for Patient-Specific Design
For this conceptual design a relatively typical chinchilla scan was used, and the stereotaxic guide was built around the bone. Even in this relatively typical chinchilla model, the germinative centers were misaligned between the two sides of the mandible, this reinforces the need for patient-specific models, as even healthy chinchilla roots are not always static in one location.

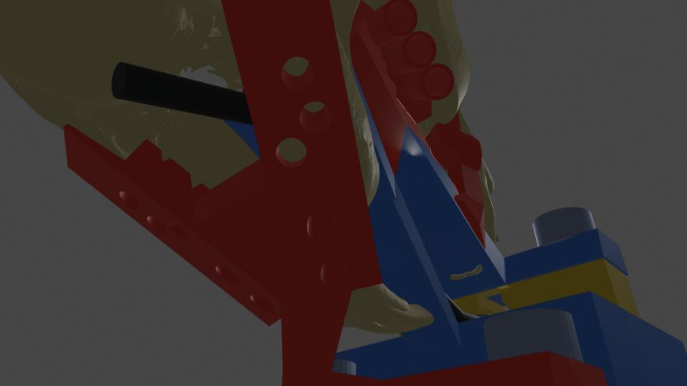
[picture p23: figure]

The above image demonstrates that the external mandibular blocks have triangular grooves running perpendicularly to the jaw, which are intended to prevent saline and blood accumulation against the skin. Additionally, there is a large gap between these blocks and the mandible as they approach the groove created by the masseter’s insertion, where the facial artery and vein are assumed to curve around the jaw to supply blood to the face due to the vascular anatomy of related species (Greene, 1935; Cooper, 1975; Natural History Museum of Los Angeles County, 2020), a detail vital to the welfare of the patient, which due to the lack of primary data, will have to be verified in the cadaver trial phase, such that adjustments can be made if necessary.

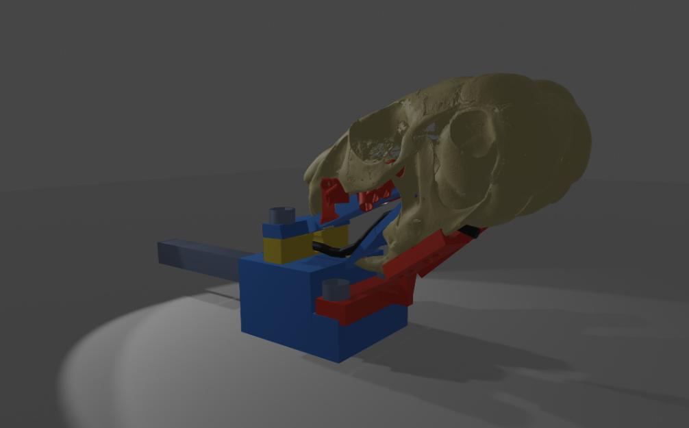
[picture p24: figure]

The external mandibular blocks could not be directly affixed to the primary structure alongside the intra-oral mandibular block, as it would make fixation of the device functionally impossible, and likely to cause structural damage which would make the guide system inaccurate. As such, the external mandible blocks are affixed to the main structure after it is inserted into the oral cavity. It is affixed using an L-shelf design that provides simplicity in preparation, ease of use, and prevents rotational motion of the blocks during surgery.

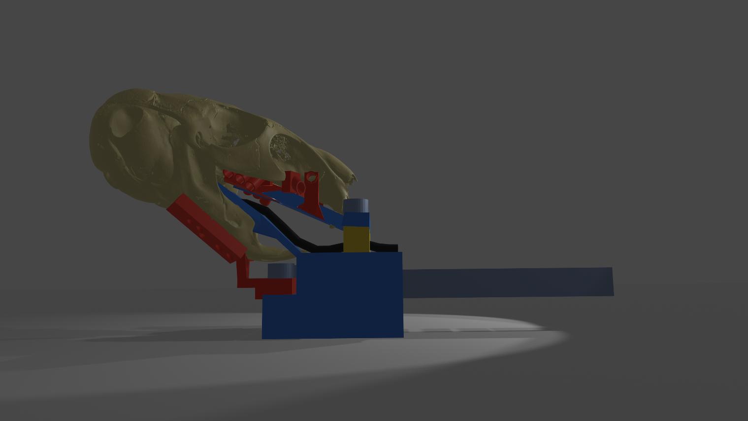
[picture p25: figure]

Some features for future designs are already in the planning phase, including the insertion of ports into drill barrels for ease of saline cooling; attachable depth-stops which physically prevent a drill from extending into the soft tissue; and an external maxillary guide that allows for treatment of maxillary cheek teeth that have undergone retrograde elongation, through a trans-orbital approach, using specialized spatulated guides with steel inlays to shield the globe from light and the drill, safely retracting and protecting the globe while accessing the alveolar floor. Notably, I believe a generalist version of this model (i.e. a version without the drill barrels and extra-mandibular guide) would be a valuable operative tool for surgeries throughout the cranium and mandible due to its stability.

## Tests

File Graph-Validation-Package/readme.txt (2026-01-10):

dGPR Monte Carlo Graph Validation

Authored and Developed by Daniel B. B. Fraser

~~~~~~~~~~~~~~~~~~~~~~~~~~~~~~~~~~~~~~~~~~~~~~~~~~~~~~~~~~~~~~~~~~~~~~~~~

Important End-User Information:

It is recommended that this package is run from the C drive of your
workstation, due to path handling issues encountered during development.
It is possible to run on separate drives, but may take manual
configuration.

Expected user inputs for each validation can be found in the
documentation of the respective sub-folders.

~~~~~~~~~~~~~~~~~~~~~~~~~~~~~~~~~~~~~~~~~~~~~~~~~~~~~~~~~~~~~~~~~~~~~~~~~

Validated Workstation Specifications:

CPU: Intel Core i7 13700kf
GPU: nVidia RTX 4090
RAM: 64GB 5200MHz DDR5

This package can be computationally intensive due to the subdivision
method used for voxelization, as such, I cannot confirm whether it would
function on a workstation with lower compute or memory capacity than the
above validated specifications.

~~~~~~~~~~~~~~~~~~~~~~~~~~~~~~~~~~~~~~~~~~~~~~~~~~~~~~~~~~~~~~~~~~~~~~~~~

Dependencies (verified with the pipreqs package):

Numpy 2.4.0

Trimesh[easy] 4.10.0

Matplotlib 3.10.8

These can be installed via the pip installer with the following
command line argument:

pip install [package name]==[version number]

For reference, Trimesh[easy] is listed for sub-dependencies.

Additionally, the Monte Carlo eXtreme - CUDA edition package version 2.8 
(v2025.10, Kilo-Kelvin), which can be found at https://mcx.space/
~~~~~~~~~~~~~~~~~~~~~~~~~~~~~~~~~~~~~~~~~~~~~~~~~~~~~~~~~~~~~~~~~~~~~~~~~

This package represents mathematical proof for the MCX graphs provided in
the Appendix section of the paper "Novel Application of Stereotaxically
Guided Dental Germinative Photodynamic Regulation in Chinchilla lanigera
with Refractory Malocclusion".

The contained files are intentionally hard-coded structures, to ensure
reproducibility in results, for validation purposes.
 
No parameter tuning or interactive input is required or expected for 
operation. This allows for the graphs to be validated with relative ease.

This package is not intended or designed for general-purpose MCX
experimentation or clinical planning.

~~~~~~~~~~~~~~~~~~~~~~~~~~~~~~~~~~~~~~~~~~~~~~~~~~~~~~~~~~~~~~~~~~~~~~~~~

Optical parameters for rabbit tissue and human pulp (considered best
available match due to lack of optical properties of Chinchilla lanigera
tissues) were sourced from the following papers:

Fu, Y & Jacques, S. L. (2011). Monte Carlo Simulation for Light Propagation
	in 3D tooth model. Optical Interactions with Tissues and Cells XXII,
	SPIE: Bellingham, WA, USA. https://doi.org/10.1117/12.873603

Shanshool, A. S. et al. (2022). Optical Properties and Fluence Distribution
	in Rabbit Head Tissues at Selected Laser Wavelengths. Materials,
	15(16), 5696. https://doi.org/10.3390/ma15165696

~~~~~~~~~~~~~~~~~~~~~~~~~~~~~~~~~~~~~~~~~~~~~~~~~~~~~~~~~~~~~~~~~~~~~~~~~

The MCX software was established in the following paper, as such, it 
covers the foundational concepts necessary for these simulations.

Fang, Q. & Boas, D. A. (2009). Monte Carlo Simulation of Photon Migration 
in 3D Turbid Media Accelerated by Graphics Processing Units. Optics 
Express, 17(22), 20178-20190. https://doi.org/10.1364/oe.17.020178

~~~~~~~~~~~~~~~~~~~~~~~~~~~~~~~~~~~~~~~~~~~~~~~~~~~~~~~~~~~~~~~~~~~~~~~~~

Segment models of the Chinchilla lanigera maxilla used were derived from 
CT data sourced from the Natural History Museum of Los Angeles County 
via Morphosource:

Natural History Museum of Los Angeles County (2020). Chinchilla lanigera 
	Skull DICOM [Data Set]. MorphoSource. 
	https://www.morphosource.org/concern/media/000114253

~~~~~~~~~~~~~~~~~~~~~~~~~~~~~~~~~~~~~~~~~~~~~~~~~~~~~~~~~~~~~~~~~~~~~~~~~

License & Copyright

This project is dual-licensed due to scope:

Software code (Python Scripts) are licenced under the GNU General Public
License v3.0 (GPLv3). You may copy, distribute, and modify the software as
long as you track the changes and release modifications under the same 
license.

Documentation and Papers (PDFs, Protocol Text, and Guide Specifications) 
are licensed under Creative Commons Attribution-ShareAlike 4.0
International (CC BY-SA 4.0). To view a copy of this license, visit 
https://creativecommons.org/licenses/by-sa/4.0/

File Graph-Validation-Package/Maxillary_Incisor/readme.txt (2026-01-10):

dGPR Monte Carlo Simulation - Maxillary Incisor

Dependencies:
Numpy 2.4.0
Trimesh[easy] 4.10.0
Matplotlib 3.10.8

~~~~~~~~~~~~~~~~~~~~~~~~~~~~~~~~~~~~~~~~~~~~~~~~~~~~~~~~~~~~~~~~~~~~~~~~~

Usage:
Filepaths may have to be adjusted for user system, original code used 
full length file paths. For ease of use, it is recommended to run from 
the C drive, as issues were encountered when running MCX using other 
drives. Programs should be run in the following order, using the 
commands provided:

cd (current working directory)

python STLtoVoxel.py

mcx --input MCXincisor.json -F mc2

python ApoptosisVisualizer

~~~~~~~~~~~~~~~~~~~~~~~~~~~~~~~~~~~~~~~~~~~~~~~~~~~~~~~~~~~~~~~~~~~~~~~~~

Explanation of MCXincisor.json:

{
  "Session": {
    "ID": "Chinchilla_25um",
    "Photons": 500000000,	#500 million photons for fluid results
    "RNGSeed": 4982598		#fixed seed for reproducibility
  },
  "Forward": {
    "T0": 0.0,			#starting position, 0 time passage
    "T1": 5e-10,		#ending position, 0.5 nanoseconds past start
    "Dt": 1e-10			#intervals, 0.1 nanoseconds per interval
  },
  "Optode": {
    "Source": {
      "Type": "isotropic",	#Isotropic source to simulate cylindrical diffuser
      "Pos": [399, 137, 101],	#center of fiber tip
      "Dir": [1.0, 0.0, 0.0],
      "Param1": [1, 1, 1, 1],
      "Param2": [0, 0, 0, 0]
    },
    "Detector": [
      { "Pos": [399, 137, 101], "R": 10.0 }	#placeholder detector
    ]
  },
  "Domain": {
    "VolumeFile": "tooth_25um_FINAL.bin",		#filepath may need user adjustment, the original code used full file paths
    "Dim": [781, 504, 366],				#grid dimensions
    "LengthUnit": 0.025,				#Voxel size
    "VolumeFormat": "C",
    "Media": [
      {"mua": 0.12,  "mus": 6.2,  "g": 0.83, "n": 1.368}, #Rabbit Neural Tissue (Shanshool et al., 2022)
      {"mua": 0.12,  "mus": 6.2,  "g": 0.83, "n": 1.368}, #Rabbit Neural Tissue (Shanshool et al., 2022)
      {"mua": 0.30,  "mus": 7.8,  "g": 0.81, "n": 1.370}, #Rabbit Cranial Bone (Shanshool et al., 2022)
      {"mua": 0.035,  "mus": 10.0,  "g": 0.97, "n": 1.370}, #Human Pulp, using n value from Rabbit tissue (Fu & Jacques, 2011; Shanshool et al., 2022)
      {"mua": 1000.0,  "mus": 100.0,  "g": 0.01, "n": 1.000}, #Resin, generic opaque
      {"mua": 1000.0,  "mus": 100.0,  "g": 0.01, "n": 1.000}, #Steel, generic opaque
      {"mua": 1000.0,  "mus": 100.0,  "g": 0.01, "n": 1.000}, #Fiber coating, generic opaque
      {"mua": 0.01,  "mus": 0.1,  "g": 0.99, "n": 1.460} #Fiber core, generic near-transparent
      {"mua": 1000.0,  "mus": 100.0,  "g": 0.01, "n": 1.000} #Fiber cap, generic opaque
    ]
  }
}

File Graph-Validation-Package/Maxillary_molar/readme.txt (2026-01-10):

dGPR Monte Carlo Simulation - Maxillary Molar

Dependencies:
Numpy 2.4.0
Trimesh[easy] 4.10.0
Matplotlib 3.10.8

~~~~~~~~~~~~~~~~~~~~~~~~~~~~~~~~~~~~~~~~~~~~~~~~~~~~~~~~~~~~~~~~~~~~~~~~~

Usage:
Filepaths may have to be adjusted for user system, original code used full
length filepaths. For ease of use, it is recommended to run from the 
C drive, as issues were encountered when running MCX using other drives. 
Programs should be run in the following order, using the commands provided:

cd (current working directory)

python STLtoVoxel.py

mcx --input MCXmaxilla.json -F mc2

python ApoptosisVisualizer

~~~~~~~~~~~~~~~~~~~~~~~~~~~~~~~~~~~~~~~~~~~~~~~~~~~~~~~~~~~~~~~~~~~~~~~~~

Explanation of MCXmaxilla.json:

{
  "Session": {
    "ID": "Chinchilla_25um",
    "Photons": 500000000,	#500 million photons for fluid results
    "RNGSeed": 4982598		#fixed seed for reproducibility
  },
  "Forward": {
    "T0": 0.0,			#starting position, 0 time passage
    "T1": 5e-9,			#ending position, 5 nanoseconds past start
    "Dt": 5e-10			#intervals, 0.5 nanoseconds per interval
  },
  "Optode": {
    "Source": {
      "Type": "isotropic",	#Isotropic source to simulate cylindrical diffuser
      "Pos": [98, 332, 226],	#center of fiber tip
      "Dir": [0.0, 0.0, 1.0],
      "Param1": [1, 1, 1, 1],
      "Param2": [0, 0, 0, 0]
    },
    "Detector": [
      { "Pos": [98, 332, 226], "R": 10.0 }	#placeholder detector
    ]
  },
  "Domain": {
    "VolumeFile": "tooth_25um_FINAL.bin",		#filepath may need user adjustment, original code used full file paths
    "Dim": [196, 584, 305],				#grid dimensions
    "LengthUnit": 0.025,				#Voxel size
    "VolumeFormat": "C",
    "Media": [
      {"mua": 0.12,  "mus": 6.2,  "g": 0.83, "n": 1.368}, #Rabbit Neural Tissue (Shanshool et al., 2022)
      {"mua": 0.12,  "mus": 6.2,  "g": 0.83, "n": 1.368}, #Rabbit Neural Tissue (Shanshool et al., 2022)
      {"mua": 0.30,  "mus": 7.8,  "g": 0.81, "n": 1.370}, #Rabbit Cranial Bone (Shanshool et al., 2022)
      {"mua": 0.035,  "mus": 10.0,  "g": 0.97, "n": 1.370}, #Human Pulp, using n value from Rabbit tissue (Fu & Jacques, 2011; Shanshool et al., 2022)
      {"mua": 1000.0,  "mus": 100.0,  "g": 0.01, "n": 1.000}, #Resin, generic opaque
      {"mua": 1000.0,  "mus": 100.0,  "g": 0.01, "n": 1.000}, #Steel, generic opaque
      {"mua": 1000.0,  "mus": 100.0,  "g": 0.01, "n": 1.000}, #Fiber coating, generic opaque
      {"mua": 0.01,  "mus": 0.1,  "g": 0.99, "n": 1.460} #Fiber core, generic near-transparent
    ]
  }
}

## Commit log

2026-01-10 Adding main content: paper and software package
    [fiberCap.stl, fiberCoated.stl, fiberUncoated.stl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]
2026-01-15 Adding printable handout.
    Adding one-page, printable handout for community outreach.
